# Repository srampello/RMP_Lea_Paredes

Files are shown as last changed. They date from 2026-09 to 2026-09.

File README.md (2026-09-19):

# RMP LEA_PAREDES

Repositorio principal de **LEA_PAREDES**, robot micromouse de competición desarrollado por RMP Robotics.

<p align="center">
  Logo LEA_PAREDES
</p>

<p align="center">
  <a href="https://rmp-robotics.santii-rampe.chatgpt.site/robots/lea-paredes">Ver página del robot</a>
</p>

## Objetivo

Diseñar un micromouse compacto capaz de recorrer laberintos de celdas de **18 × 18 cm**, comenzando con seguimiento de pared derecha y giros temporizados, para evolucionar posteriormente hacia navegación autónoma y resolución de laberintos.

## Configuración actual

- ESP32-C3 Super Mini
- Driver dual TB6612FNG
- 2 × motores Pololu 1000 RPM
- Ruedas de 26 mm
- 4 pares de sensores infrarrojos:
  - 2 frontales
  - 1 lateral derecho
  - 1 lateral izquierdo
- Turbina con motor coreless 8520 y fan de 30 mm
- LiPo 2S 7,4 V con conector XT30
- Matek MICRO BEC 6–30 V ajustado a 5 V
- Capacitor de 470 µF / 25 V sobre la alimentación principal
- Base impresa en 3D y PCB superior

## Arquitectura

- **VBAT / 2S:** TB6612FNG, motores de tracción y etapa de potencia de la turbina.
- **5 V:** Matek MICRO BEC → ESP32-C3 y bloques que requieran alimentación regulada.
- **3,3 V:** lógica y señales compatibles con la ESP32-C3.
- **GND:** masa común para todos los módulos.

## Navegación inicial

La primera estrategia de control sigue la regla de la pared derecha:

1. Mantener una distancia de referencia respecto de la pared derecha.
2. Corregir la trayectoria mediante control diferencial de motores.
3. Detectar paredes frontales con los sensores delanteros.
4. Ejecutar giros temporizados durante las primeras pruebas.
5. Incorporar navegación con mapa y encoders en futuras revisiones.

## Estado del proyecto

El diseño mecánico se encuentra en evolución. La primera base impresa integra motores, batería y turbina; la electrónica se monta sobre una PCB superior. Por el momento, los motores se utilizan **sin encoders**.

## Documentación

- [Arquitectura del sistema](docs/ARQUITECTURA.md)
- [Conexiones actuales](docs/CONEXIONES.md)
- [Firmware](firmware/README.md)
- [Hardware electrónico](hardware/README.md)
- [Diseño mecánico y CAD](cad/README.md)
- [Lista de materiales](bom/README.md)
- [Changelog](CHANGELOG.md)
- [Página pública de RMP Robotics](https://rmp-robotics.santii-rampe.chatgpt.site/robots/lea-paredes)

## Estructura

```text
RMP_Lea_Paredes/
├── docs/
├── firmware/
│   ├── pruebas/
│   └── lea_paredes/
├── hardware/
│   ├── esquematicos/
│   └── pcb/
├── cad/
├── bom/
└── images/
    ├── components/
    ├── logos/
    └── lea-paredes/
```

El objetivo es mantener en un único repositorio el firmware, los esquemáticos, el diseño de PCB, los modelos CAD, la lista de materiales y toda la documentación técnica de LEA_PAREDES.

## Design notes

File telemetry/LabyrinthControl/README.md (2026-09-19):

# Labyrinth Control v1

Panel de puesta a punto para Windows y firmware de prueba para un robot con
ESP32-S3 SuperMini y DRV8833.

## Qué permite hacer

- Conectarse al robot por Wi-Fi directo.
- Regular por separado la velocidad de cada motor (0 a 255).
- Avanzar, retroceder y girar mientras se mantiene presionado el control.
- Invertir el sentido de cada motor desde la interfaz, sin cambiar cables.
- Usar las teclas `W`, `A`, `S`, `D` y `Espacio`.
- Detener automáticamente los motores si se pierde la comunicación.

## 1. Cargar el firmware en el ESP32-S3

1. Abrir `firmware/firmware_esp32_s3.ino` con Arduino IDE.
2. Seleccionar la placa ESP32-S3 correspondiente y su puerto COM.
3. Compilar y cargar.
4. Dejar inicialmente las ruedas levantadas del suelo.

Pinout utilizado:

| Función | GPIO |
|---|---:|
| Motor izquierdo IN1 | 5 |
| Motor izquierdo IN2 | 6 |
| Motor derecho IN3 | 7 |
| Motor derecho IN4 | 8 |

El pin `SLEEP` del DRV8833 debe estar conectado a `3V3`, tal como figura en el
esquema del robot.

## 2. Conectar Windows al robot

En la lista de redes Wi-Fi de Windows:

- Red: `LABERINTO-ESP32`
- Contraseña: `robot1234`

Windows puede indicar que la red no tiene Internet. Es normal: es una conexión
directa entre la notebook y el robot.

## 3. Abrir la aplicación

Con Python 3 instalado, ejecutar `iniciar.bat`. La aplicación usa únicamente
módulos incluidos con Python; no necesita instalar paquetes adicionales.

1. Mantener la IP `192.168.4.1`.
2. Pulsar **CONECTAR**.
3. Elegir velocidades bajas, por ejemplo 80–100.
4. Mantener presionado un botón de movimiento.
5. Soltarlo para detener los motores.

Si una rueda avanza al revés, activar **Invertir sentido** en ese motor.

## Seguridad

- El botón **STOP** y la barra espaciadora envían una parada inmediata.
- El firmware detiene los motores si pasan 800 ms sin recibir una orden.
- Al cerrar la ventana, la aplicación intenta detener ambos motores.
- La primera prueba debe realizarse con las ruedas en el aire.

## Crear un `.exe` opcional

Ejecutar `crear_exe.bat`. El script instala PyInstaller si hace falta y genera:

`dist/LabyrinthControl.exe`

El `.exe` puede copiarse a otra PC con Windows y no requiere Python instalado.

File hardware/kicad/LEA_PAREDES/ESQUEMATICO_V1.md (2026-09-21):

# LEA_PAREDES — Esquemático V1

Primera versión editable del circuito para KiCad. El objetivo es que sirva como
base de trabajo y que luego pueda ajustarse con mediciones reales, experiencia
de pista y los componentes físicos.

## Arquitectura eléctrica

- Batería Tattu LiHV 2S 300 mAh: `VBAT` (7,6 V nominal, 8,7 V completamente cargada).
- `VBAT` alimenta directamente `VM` del TB6612FNG y la entrada del Matek Micro BEC.
- Matek configurado a 5 V: genera `+5V_RAW` para emisores IR y turbina.
- Un SS14 separa `+5V_RAW` de `ESP_5V`, reduciendo el riesgo de realimentar el resto
  del robot al conectar USB al ESP32-C3.
- El regulador de 3,3 V del módulo ESP32 genera `+3V3` para lógica, TB6612 y receptores.
- Todas las masas están unidas en `GND`.

## Pines del ESP32-C3 Super Mini

| GPIO | Función | Observación |
|---:|---|---|
| 0 | ADC sensor frontal izquierdo | `SENS_FL` |
| 1 | ADC sensor frontal derecho | `SENS_FR` |
| 2 | PWM motor izquierdo | `PWM_A`; pin de strap, pull-up de 10 kΩ |
| 3 | ADC sensor lateral izquierdo | `SENS_L` |
| 4 | ADC sensor lateral derecho | `SENS_R` |
| 5 | Dirección A1 | `AIN1` |
| 6 | Dirección A2 | `AIN2` |
| 7 | Dirección B1 | `BIN1` |
| 8 | PWM motor derecho | `PWM_B`; pin de strap y LED integrado en muchas placas |
| 9 | Pulsador de inicio | también es `BOOT`; no mantener pulsado durante reset |
| 10 | Dirección B2 | `BIN2` |
| 20 | PWM turbina | `FAN_PWM` |
| 21 | Encendido común de emisores IR | `IR_EN` |

`PWMA` y `PWMB` no están conectados permanentemente a 3,3 V. Ambos llegan al
ESP32 para usar PWM convencional del TB6612. Los pull-up de 10 kΩ sólo fijan un
estado seguro durante el arranque y no impiden que el ESP32 genere PWM.

## Sensores infrarrojos

Hay cuatro pares: frontal izquierdo, frontal derecho, lateral izquierdo y
lateral derecho.

- Cada TSAL6100 recibe 5 V mediante dos resistencias de 150 Ω en paralelo
  (75 Ω equivalentes). Al pasar de tres a cuatro emisores hacen falta **ocho
  resistencias de 150 Ω**, no seis.
- Los cuatro cátodos se conmutan juntos mediante un AO3400A en el lado bajo.
- Cada PT334-6B tiene colector a 3,3 V, emisor al ADC y 10 kΩ del ADC a GND.
- Confirmar la identificación física de ánodo/cátodo y colector/emisor con los
  datasheets y una prueba de banco antes de fabricar la PCB.

## Turbina

- Motor coreless 8520 conectado a `+5V_TURBINE`.
- AO3400A en conmutación low-side, resistencia de gate de 100 Ω y pull-down de
  10 kΩ.
- Diodo SS34 de rueda libre, cátodo al positivo del motor.
- `SJ1` une `+5V_RAW` con `+5V_TURBINE` y queda cerrado por defecto. Si más
  adelante la turbina necesita otro regulador, se abre el puente y se inyecta
  allí la nueva alimentación.
- `C7` de 470 µF está marcado DNP/opcional; se coloca sólo si las pruebas muestran
  caídas o ruido importantes y el Matek tolera el pico de arranque.
- Empezar las pruebas con límite de PWM alrededor de 70 % y rampa de arranque.

## Advertencias para la primera PCB

1. Verificar con multímetro la polaridad real del JST-PH de la batería. En el
   esquema se define `J1.1 = BAT+` y `J1.2 = GND`.
2. Mantener abierto el puente de 9 V del Matek para obtener 5 V.
3. Los motores nominales de 6 V reciben `VBAT` a través del TB6612. Aunque se
   probaron a PWM 255, revisar corriente de bloqueo y temperatura; el firmware
   debería usar rampa y, si hace falta, limitar duty.
4. La capacidad nominal del Matek es 1,5 A continua. Medir el consumo conjunto
   de turbina, IR y lógica antes de dar por cerrada la alimentación.
5. Confirmar huellas físicas del JST-PH, capacitor electrolítico, pulsador,
   TSAL6100 y PT334-6B antes del ruteo final.

## Regeneración

El archivo `tools/generate_schematic.py` reconstruye tanto
`LEA_PAREDES.kicad_sch` como `LEA_PAREDES.kicad_sym`. Abrir el `.kicad_sch` en
KiCad y guardarlo una vez permite que KiCad lo actualice automáticamente a la
versión instalada.

La validación automática incluida comprueba balance de S-expressions y que
todos los pines de cada símbolo tengan una red asignada. Todavía es necesario
ejecutar ERC desde KiCad después de abrirlo y revisar manualmente las huellas.

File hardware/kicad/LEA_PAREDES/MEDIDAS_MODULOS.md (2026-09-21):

# Medidas y orientación de módulos

Estas huellas se prepararon a partir de las fotografías de los módulos reales y de sus dimensiones nominales.

| Módulo | Cuerpo nominal | Paso vertical | Separación entre hileras |
|---|---:|---:|---:|
| ESP32-C3 Super Mini | 18,0 × 22,5 mm | 2,54 mm | 15,24 mm |
| TB6612FNG rojo genérico | 18,0 × 20,5 mm | 2,54 mm | 15,24 mm |
| Matek Micro BEC 6–30 V | 14,0 × 10,0 mm | 2,54 mm | Una hilera de 4 pads |
| AO3400/AO3400A | SOT-23 | — | — |

## Orientación

- ESP32: vista desde arriba, componentes visibles y USB-C hacia arriba. La antena queda abajo. No colocar cobre, pistas ni vías bajo la zona marcada `ANTENNA_KEEP_OUT`.
- TB6612FNG: vista desde arriba, integrado visible, capacitor hacia arriba y el texto `TB6612FNG` legible abajo.
- Matek Micro BEC: vista de componentes hacia arriba y pads al lado izquierdo. De arriba hacia abajo: `5V_OUT`, `GND1`, `GND2`, `VIN_6-30V`. El puente `9V` debe permanecer abierto para obtener 5 V.
- Los nombres de los pads coinciden con el texto funcional del módulo para reducir errores de asignación.

## Montaje recomendado

Para el micromouse se recomienda la variante `Castellated`, soldada directamente sobre la PCB: es más baja, liviana y resistente a vibraciones. Las variantes `THT` quedan para prototipo o módulos reemplazables.

## Pendientes antes de fabricar

1. Imprimir las huellas a escala 1:1 y apoyar físicamente ambos módulos.
2. Confirmar con multímetro los tres GND del TB6612FNG y la orientación indicada.
3. Confirmar el Matek con una impresión 1:1. Como sus cuatro pads están en un único lateral, sujetarlo además con una pequeña cantidad de silicona neutra o adhesivo flexible después de soldarlo.
4. Verificar con multímetro que el Matek entregue 5 V antes de instalar la ESP32-C3.
5. El AO3400 usa el SOT-23 estándar de KiCad: `Package_TO_SOT_SMD:SOT-23`, con 1=G, 2=S y 3=D.

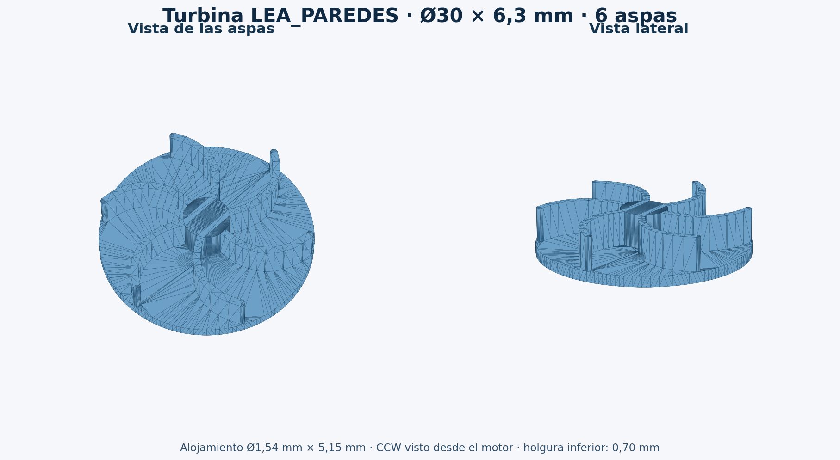
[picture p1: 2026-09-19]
3d_chatgpt/Vista_previa_Turbina_LEA_PAREDES.png

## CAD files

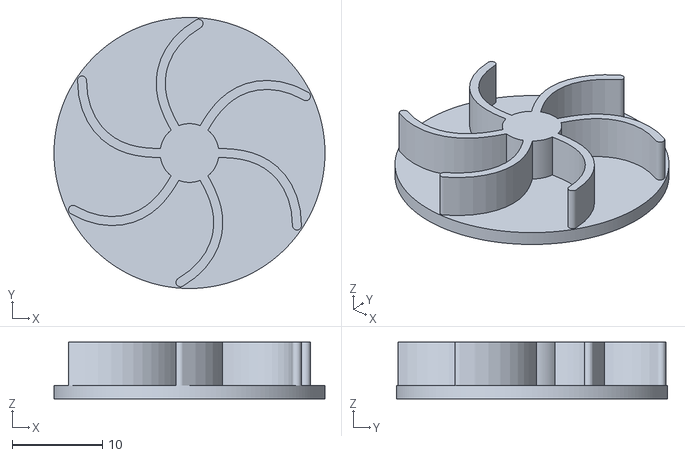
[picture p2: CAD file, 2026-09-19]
3d_chatgpt/Turbina_LEA_PAREDES_30mm_CW.stl
30.0 x 30.0 x 6.30

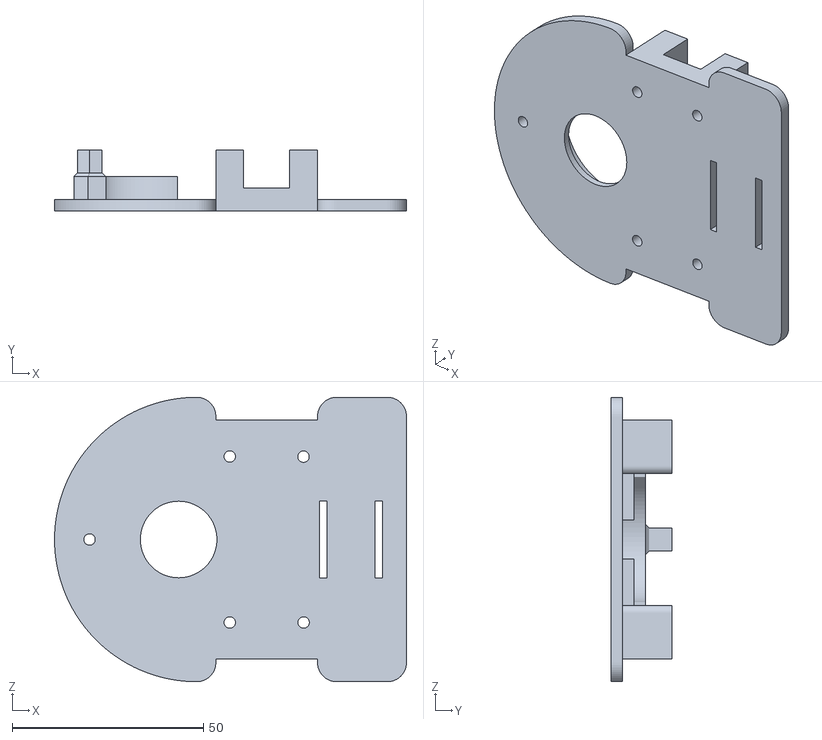
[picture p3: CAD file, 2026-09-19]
3d_stl/base.stl
91.9 x 16.0 x 74.3

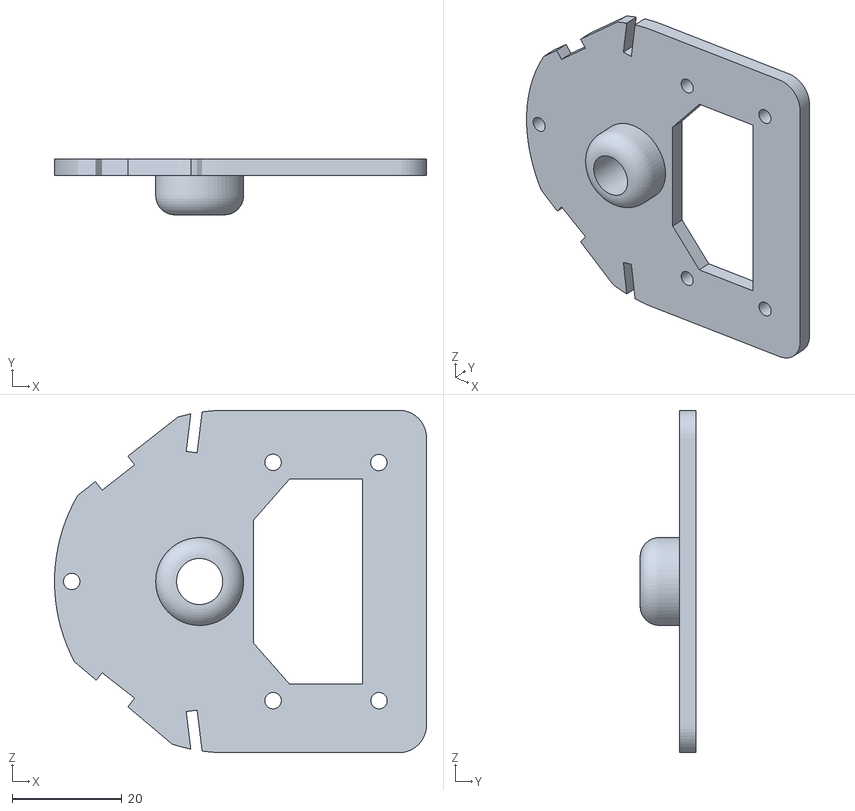
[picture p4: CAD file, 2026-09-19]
3d_stl/base_superipor.stl
67.7 x 10.1 x 62.3

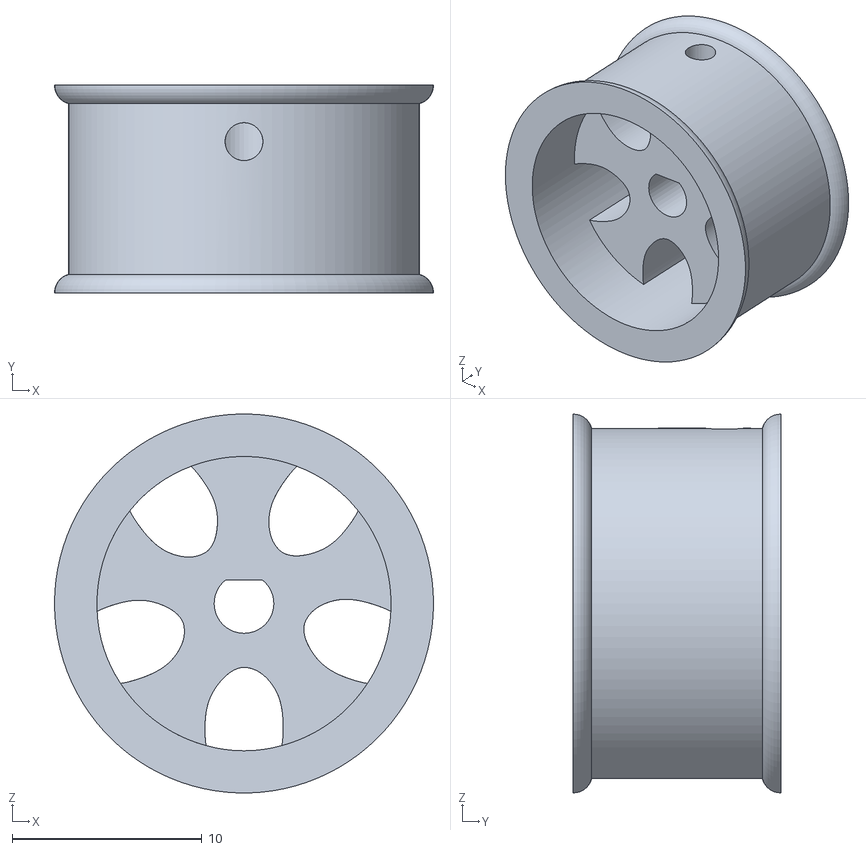
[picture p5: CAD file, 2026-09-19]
3d_stl/Rueda_Micromouse.stl
20.0 x 11.0 x 20.0

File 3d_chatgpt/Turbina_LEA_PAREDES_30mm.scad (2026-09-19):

/*
  Turbina centrifuga para LEA_PAREDES
  Motor: coreless 8520

  Dimensiones principales:
    - Diametro exterior: 30.0 mm
    - Altura total: 6.3 mm
    - Disco posterior: 1.5 mm
    - Altura de aspas: 4.8 mm
    - Cantidad de aspas: 6
    - Orificio del eje: 1.54 mm nominal
    - Profundidad del orificio: 5.15 mm (ciego)

  El sentido se define mirando la turbina desde el lado del motor/disco.
  Valores permitidos: "CCW" o "CW".
*/

$fn = 160;

rotation_direction = "CCW";

impeller_diameter = 30.0;
backplate_thickness = 1.5;
blade_height = 4.8;
blade_count = 6;
blade_thickness = 1.0;
blade_inner_radius = 3.0;
blade_outer_radius = 14.35;
blade_sweep_degrees = 34;
hub_diameter = 6.5;
shaft_hole_diameter = 1.54;
shaft_hole_depth = 5.15;

total_height = backplate_thickness + blade_height;

// El observador esta del lado del motor (cara plana, z negativo).
// Esa vista invierte el sentido aparente respecto de la vista de las aspas.
direction_sign = rotation_direction == "CCW" ? 1 : -1;

module polar_disc(radius, angle, diameter, height) {
    translate([radius * cos(angle), radius * sin(angle), backplate_thickness])
        cylinder(d = diameter, h = height, $fn = 24);
}

// Aspa curvada hacia atras, construida mediante segmentos tangentes.
module curved_blade_2d() {
    steps = 12;
    for (index = [0 : steps - 1]) {
        radius_1 = blade_inner_radius
            + (blade_outer_radius - blade_inner_radius) * index / steps;
        radius_2 = blade_inner_radius
            + (blade_outer_radius - blade_inner_radius) * (index + 1) / steps;

        // Curvatura progresiva: suave en la entrada y mas marcada en la salida.
        progress_1 = index / steps;
        progress_2 = (index + 1) / steps;
        angle_1 = direction_sign * blade_sweep_degrees * progress_1 * progress_1;
        angle_2 = direction_sign * blade_sweep_degrees * progress_2 * progress_2;

        hull() {
            translate([radius_1 * cos(angle_1), radius_1 * sin(angle_1)])
                circle(d = blade_thickness, $fn = 20);
            translate([radius_2 * cos(angle_2), radius_2 * sin(angle_2)])
                circle(d = blade_thickness, $fn = 20);
        }
    }
}

module impeller_body() {
    union() {
        // Disco cerrado que recibe el eje del motor.
        cylinder(d = impeller_diameter, h = backplate_thickness);

        // Cubo central: une las seis aspas y refuerza el alojamiento del eje.
        cylinder(d = hub_diameter, h = total_height);

        // Seis aspas equidistantes para conservar el balance dinamico.
        for (blade = [0 : blade_count - 1]) {
            rotate([0, 0, blade * 360 / blade_count])
                translate([0, 0, backplate_thickness])
                    linear_extrude(height = blade_height)
                        curved_blade_2d();
        }
    }
}

difference() {
    impeller_body();

    // Alojamiento ciego: entrada desde la cara plana del disco.
    // Se deja material en el extremo para que el eje no atraviese la turbina.
    translate([0, 0, -0.05])
        cylinder(d = shaft_hole_diameter,
                 h = shaft_hole_depth + 0.05,
                 $fn = 64);
}

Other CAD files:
3d_stl/turb_30mm.stl
3d_chatgpt/Turbina_LEA_PAREDES_30mm_CCW.stl
fusion_archive/Rueda_Micromouse.f3d
fusion_archive/base.f3d
fusion_archive/turb_30mm.f3d

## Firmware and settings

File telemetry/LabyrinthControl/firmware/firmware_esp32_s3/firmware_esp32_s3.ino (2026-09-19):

/*
 * LABYRINTH CONTROL - firmware de prueba de motores
 * ESP32-S3 SuperMini + DRV8833
 *
 * Red Wi-Fi creada por el robot:
 *   SSID: LABERINTO-ESP32
 *   Clave: robot1234
 *   IP: 192.168.4.1
 */

#include <WiFi.h>
#include <WebServer.h>

// DRV8833
constexpr uint8_t M1_IN1 = 5;
constexpr uint8_t M1_IN2 = 6;
constexpr uint8_t M2_IN1 = 7;
constexpr uint8_t M2_IN2 = 8;

constexpr char AP_SSID[] = "LABERINTO-ESP32";
constexpr char AP_PASSWORD[] = "robot1234";

// Si la app deja de enviar órdenes, se detiene automáticamente.
constexpr uint32_t COMMAND_TIMEOUT_MS = 800;

WebServer server(80);

int motorLeft = 0;
int motorRight = 0;
uint32_t lastCommandMs = 0;


void writeMotor(uint8_t in1, uint8_t in2, int speedValue) {
  speedValue = constrain(speedValue, -255, 255);

  if (speedValue > 0) {
    analogWrite(in1, speedValue);
    analogWrite(in2, 0);
  } else if (speedValue < 0) {
    analogWrite(in1, 0);
    analogWrite(in2, -speedValue);
  } else {
    // Coast: ambas entradas en LOW.
    analogWrite(in1, 0);
    analogWrite(in2, 0);
  }
}


void setMotors(int left, int right) {
  motorLeft = constrain(left, -255, 255);
  motorRight = constrain(right, -255, 255);
  writeMotor(M1_IN1, M1_IN2, motorLeft);
  writeMotor(M2_IN1, M2_IN2, motorRight);
}


String statusJson() {
  String json = "{";
  json += "\"ok\":true,";
  json += "\"left\":" + String(motorLeft) + ",";
  json += "\"right\":" + String(motorRight) + ",";
  json += "\"clients\":" + String(WiFi.softAPgetStationNum()) + ",";
  json += "\"uptime_ms\":" + String(millis());
  json += "}";
  return json;
}


void sendJson(int code, const String &json) {
  server.sendHeader("Access-Control-Allow-Origin", "*");
  server.send(code, "application/json", json);
}


void handleStatus() {
  sendJson(200, statusJson());
}


void handleMotors() {
  if (!server.hasArg("left") || !server.hasArg("right")) {
    sendJson(400, "{\"ok\":false,\"error\":\"Faltan left y right\"}");
    return;
  }

  setMotors(server.arg("left").toInt(), server.arg("right").toInt());
  lastCommandMs = millis();
  sendJson(200, statusJson());
}


void handleStop() {
  setMotors(0, 0);
  lastCommandMs = millis();
  sendJson(200, statusJson());
}


void handleNotFound() {
  sendJson(404, "{\"ok\":false,\"error\":\"Ruta no encontrada\"}");
}


void setup() {
  pinMode(M1_IN1, OUTPUT);
  pinMode(M1_IN2, OUTPUT);
  pinMode(M2_IN1, OUTPUT);
  pinMode(M2_IN2, OUTPUT);
  setMotors(0, 0);

  Serial.begin(115200);
  delay(250);

  WiFi.mode(WIFI_AP);
  WiFi.softAP(AP_SSID, AP_PASSWORD);

  Serial.println();
  Serial.println("LABYRINTH CONTROL iniciado");
  Serial.print("Red: ");
  Serial.println(AP_SSID);
  Serial.print("IP: ");
  Serial.println(WiFi.softAPIP());

  server.on("/status", HTTP_GET, handleStatus);
  server.on("/motors", HTTP_POST, handleMotors);
  server.on("/stop", HTTP_POST, handleStop);
  server.onNotFound(handleNotFound);
  server.begin();

  lastCommandMs = millis();
}


void loop() {
  server.handleClient();

  if ((motorLeft != 0 || motorRight != 0) &&
      millis() - lastCommandMs > COMMAND_TIMEOUT_MS) {
    setMotors(0, 0);
  }

  delay(1);
}

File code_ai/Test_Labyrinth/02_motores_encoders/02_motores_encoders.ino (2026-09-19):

/*
 * PRUEBA 2 - MOTORES CON ENCODERS
 * ESP32-S3 SuperMini + DRV8833 + 2 encoders de cuadratura
 *
 * Esta prueba mueve un motor por vez y muestra los pulsos cada 250 ms.
 * No calcula RPM porque primero hay que confirmar la cantidad exacta de
 * pulsos por vuelta del motorreductor instalado.
 *
 * IMPORTANTE: hacer la primera prueba con las ruedas en el aire.
 */

// DRV8833
constexpr uint8_t M1_IN1 = 5;
constexpr uint8_t M1_IN2 = 6;
constexpr uint8_t M2_IN1 = 7;
constexpr uint8_t M2_IN2 = 8;

// Encoder izquierdo
constexpr uint8_t ENC_IZQ_A = 9;   // Cable verde C1
constexpr uint8_t ENC_IZQ_B = 10;  // Cable amarillo C2

// Encoder derecho
constexpr uint8_t ENC_DER_A = 11;  // Cable verde C1
constexpr uint8_t ENC_DER_B = 12;  // Cable amarillo C2

constexpr int PWM_PRUEBA = 80;
constexpr uint32_t DURACION_PRUEBA_MS = 3000;
constexpr uint32_t PERIODO_REPORTE_MS = 250;

// Ajustar estos valores después de observar la primera prueba.
constexpr bool INVERTIR_MOTOR_IZQ = false;
constexpr bool INVERTIR_MOTOR_DER = false;
constexpr bool INVERTIR_ENCODER_IZQ = false;
constexpr bool INVERTIR_ENCODER_DER = false;

volatile int32_t pulsosIzquierdo = 0;
volatile int32_t pulsosDerecho = 0;


void IRAM_ATTR encoderIzquierdoISR() {
  int paso = digitalRead(ENC_IZQ_B) ? 1 : -1;
  pulsosIzquierdo += INVERTIR_ENCODER_IZQ ? -paso : paso;
}


void IRAM_ATTR encoderDerechoISR() {
  int paso = digitalRead(ENC_DER_B) ? 1 : -1;
  pulsosDerecho += INVERTIR_ENCODER_DER ? -paso : paso;
}


void escribirMotor(uint8_t in1, uint8_t in2, int velocidad) {
  velocidad = constrain(velocidad, -255, 255);

  if (velocidad > 0) {
    analogWrite(in1, velocidad);
    analogWrite(in2, 0);
  } else if (velocidad < 0) {
    analogWrite(in1, 0);
    analogWrite(in2, -velocidad);
  } else {
    analogWrite(in1, 0);
    analogWrite(in2, 0);
  }
}


void motores(int izquierdo, int derecho) {
  escribirMotor(M1_IN1, M1_IN2,
                INVERTIR_MOTOR_IZQ ? -izquierdo : izquierdo);
  escribirMotor(M2_IN1, M2_IN2,
                INVERTIR_MOTOR_DER ? -derecho : derecho);
}


void detener() {
  motores(0, 0);
}


void ponerContadoresEnCero() {
  noInterrupts();
  pulsosIzquierdo = 0;
  pulsosDerecho = 0;
  interrupts();
}


void leerContadores(int32_t &izquierdo, int32_t &derecho) {
  noInterrupts();
  izquierdo = pulsosIzquierdo;
  derecho = pulsosDerecho;
  interrupts();
}


void probarMovimiento(const char *nombre, int velocidadIzq, int velocidadDer) {
  ponerContadoresEnCero();

  Serial.println();
  Serial.println(nombre);
  Serial.printf("PWM logico: IZQ=%d  DER=%d\n", velocidadIzq, velocidadDer);
  Serial.println("Tiempo(ms)\tPulsos IZQ\tPulsos DER\tDelta IZQ\tDelta DER");

  int32_t anteriorIzq = 0;
  int32_t anteriorDer = 0;
  uint32_t inicio = millis();
  uint32_t proximoReporte = inicio;

  motores(velocidadIzq, velocidadDer);

  while (millis() - inicio < DURACION_PRUEBA_MS) {
    if ((int32_t)(millis() - proximoReporte) >= 0) {
      int32_t actualIzq;
      int32_t actualDer;
      leerContadores(actualIzq, actualDer);

      Serial.printf("%lu\t\t%ld\t\t%ld\t\t%ld\t\t%ld\n",
                    millis() - inicio,
                    (long)actualIzq,
                    (long)actualDer,
                    (long)(actualIzq - anteriorIzq),
                    (long)(actualDer - anteriorDer));

      anteriorIzq = actualIzq;
      anteriorDer = actualDer;
      proximoReporte += PERIODO_REPORTE_MS;
    }
    delay(1);
  }

  detener();
  int32_t totalIzq;
  int32_t totalDer;
  leerContadores(totalIzq, totalDer);
  Serial.printf("STOP - Totales: IZQ=%ld  DER=%ld\n",
                (long)totalIzq, (long)totalDer);
  delay(1500);
}


void setup() {
  Serial.begin(115200);

  pinMode(M1_IN1, OUTPUT);
  pinMode(M1_IN2, OUTPUT);
  pinMode(M2_IN1, OUTPUT);
  pinMode(M2_IN2, OUTPUT);
  detener();

  // Los encoders están alimentados a 3V3. Si el módulo ya incorpora
  // resistencias de salida, INPUT también puede utilizarse.
  pinMode(ENC_IZQ_A, INPUT_PULLUP);
  pinMode(ENC_IZQ_B, INPUT_PULLUP);
  pinMode(ENC_DER_A, INPUT_PULLUP);
  pinMode(ENC_DER_B, INPUT_PULLUP);

  // Se cuenta un pulso por cada flanco ascendente del canal A.
  attachInterrupt(digitalPinToInterrupt(ENC_IZQ_A), encoderIzquierdoISR, RISING);
  attachInterrupt(digitalPinToInterrupt(ENC_DER_A), encoderDerechoISR, RISING);

  delay(3000);
  Serial.println("========================================");
  Serial.println("PRUEBA 2: MOTORES + ENCODERS");
  Serial.println("Monitor serie: 115200 baudios");
  Serial.println("========================================");
}


void loop() {
  probarMovimiento("1/4 - Motor IZQUIERDO positivo", PWM_PRUEBA, 0);
  probarMovimiento("2/4 - Motor IZQUIERDO negativo", -PWM_PRUEBA, 0);
  probarMovimiento("3/4 - Motor DERECHO positivo", 0, PWM_PRUEBA);
  probarMovimiento("4/4 - Motor DERECHO negativo", 0, -PWM_PRUEBA);

  Serial.println();
  Serial.println("Ciclo terminado. Se repite en 5 segundos.");
  detener();
  delay(5000);
}

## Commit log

2026-09-19 Inicializar documentación de LEA_PAREDES
2026-09-19 Agregar diseños 3D, pruebas y telemetría de LEA_PAREDES
    [Rueda_Micromouse.f3d, Rueda_Micromouse.stl, Turbina_LEA_PAREDES_30mm.scad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]
2026-09-21 Crear proyecto KiCad de LEA_PAREDES
    [LEA_PAREDES.kicad_pcb, LEA_PAREDES.kicad_sch]
2026-09-21 Dejar de versionar preferencias locales de KiCad
2026-09-21 Agregar ESP32-C3_SuperMini_Castellated.kicad_mod
2026-09-21 Agregar ESP32-C3_SuperMini_THT.kicad_mod
2026-09-21 Agregar TB6612FNG_Module_Castellated.kicad_mod
2026-09-21 Agregar TB6612FNG_Module_THT.kicad_mod
2026-09-21 Agregar esquemático eléctrico completo v1
    [LEA_PAREDES.kicad_sch]
2026-09-21 Agregar biblioteca local de símbolos
2026-09-21 Registrar biblioteca local de símbolos
2026-10-30 Enlazar la ficha técnica en el sitio de RMP Robotics
    Claude-Session: https://claude.ai/code/session_01Add55h1noW2UDnTMLgEgbK
2026-10-30 Página propia del robot con la estética de RMP Robotics
    Vitrina por sistemas e informe técnico, generados desde
    srampello/RMP (tools/web/build_site.py). No editar index.html a mano.
    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
2026-10-30 Ajustar el tamaño del título para nombres largos
    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
